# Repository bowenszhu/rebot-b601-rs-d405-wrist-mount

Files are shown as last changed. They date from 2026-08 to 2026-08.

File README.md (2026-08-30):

# reBot B601-RS RealSense D405 Wrist Mount

[简体中文](README.zh-CN.md) · [STEP/STL](hardware/release/) · [Design rationale](docs/design-rationale.md) · [Validation](docs/validation.md) · [Photo gallery](docs/photo-gallery.md)

<p align="center">
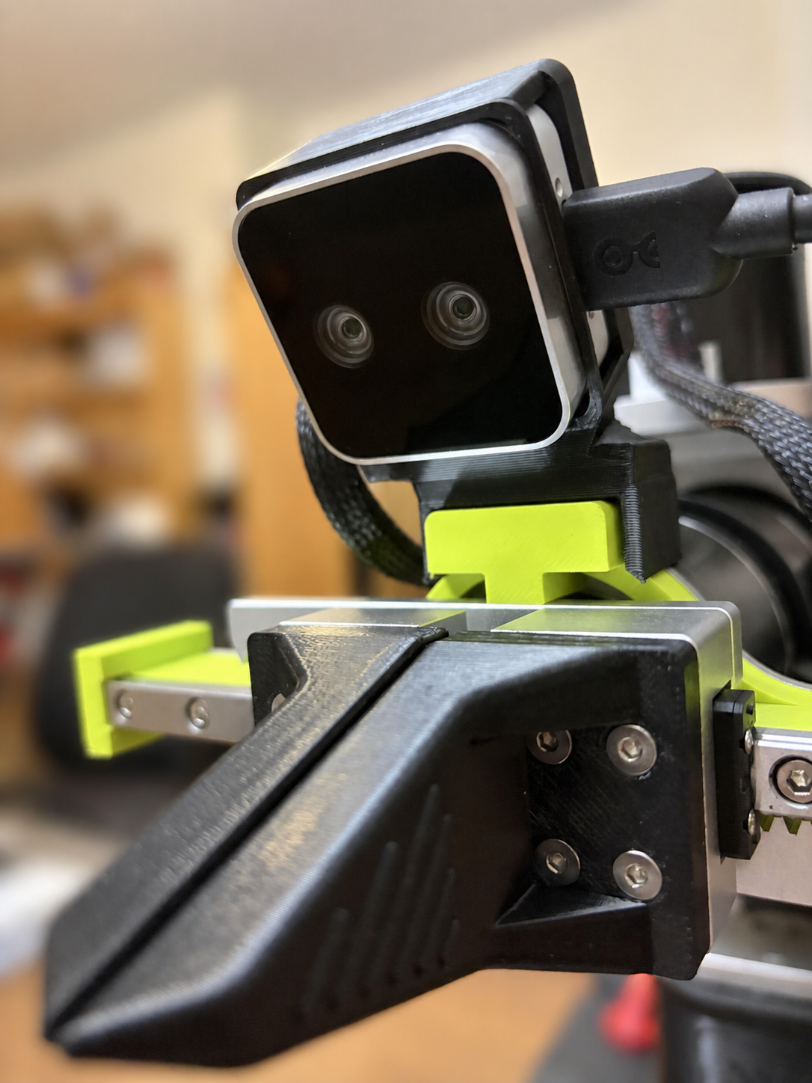
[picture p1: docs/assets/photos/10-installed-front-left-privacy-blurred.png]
30-degree D405 mount installed on the reBot B601-RS
  
</p>

A B601-RS-specific, open-hardware **30° downward eye-in-hand mount** for the [Seeed reBot Arm B601-RS](https://github.com/Seeed-Projects/reBot-DevArm) and [RealSense D405](https://www.realsenseai.com/products/stereo-depth-camera-d405/).

The design preserves Seeed's full D405 cradle and B601 wrist interface, then applies:

- **30° fixed downward pitch** — the largest integer pitch satisfying both tested clearance and working-distance boundaries at this fixed location;
- **9 mm lateral shift** — aligns the D405 left-imager optical reference, rather than the aluminium housing center, with the gripper centerline;
- **6 mm lift** — preserves conservative lower-front camera clearance as pitch increases;
- **solid lofted transition** — fills the side notch and creates a substantial load path;
- **unchanged handedness and USB side** — the cradle is not mirrored.

> “Best” means the best **validated general-purpose compromise under the stated B601-RS geometry and constraints**. It is not a universal optimum for every task or pose.

## Stock vs redesigned mount

| Seeed-derived stock ~15° | Redesigned 30° |
| --- | --- |
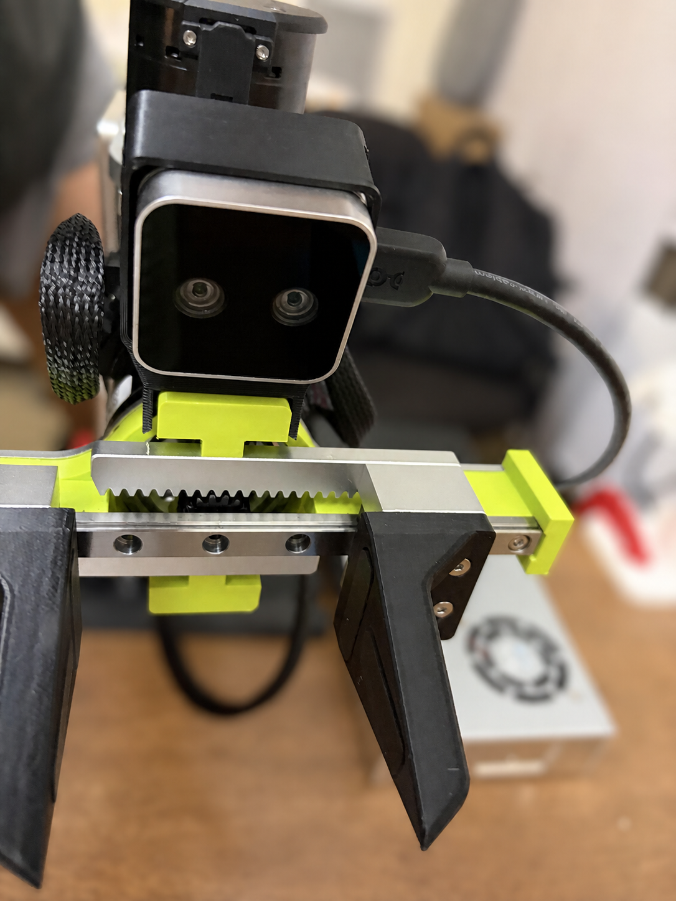
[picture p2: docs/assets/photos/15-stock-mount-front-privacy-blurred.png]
Stock mount
|  | Redesigned mount |

The upstream source is Seeed's [`D405_305_Mount.step`](https://github.com/Seeed-Projects/reBot-DevArm/blob/590ff16c51099a15a34abb339c6364355fde9235/hardware/reBot_B601_DM/3D_Printed_Parts/D405_305_Mount.step) at pinned commit [`590ff16c51099a15a34abb339c6364355fde9235`](https://github.com/Seeed-Projects/reBot-DevArm/tree/590ff16c51099a15a34abb339c6364355fde9235). Although that file lives under Seeed's B601-DM directory, the compatible interface and this derivative were physically fitted on the **B601-RS** shown here. This repository does not claim B601-DM validation.

## Download

| File | Use |
| --- | --- |
| [STEP](hardware/release/rebot_b601_rs_d405_mount_30deg.step) | Preferred manufacturing/CAD file |
| [STL](hardware/release/rebot_b601_rs_d405_mount_30deg.stl) | Ready-to-slice mesh |
| [geometry JSON](hardware/release/rebot_b601_rs_d405_mount_30deg.geometry.json) | Machine-readable pose, dimensions, and validation metadata |

[GitHub Release v1.0.0](https://github.com/bowenszhu/rebot-b601-rs-d405-wrist-mount/releases/tag/v1.0.0) contains the same three files.

Physically manufactured examples used:

- PETG, standard FDM, 100% infill, black;
- ABS, standard FDM, 60% infill, black.

See [printing and installation](docs/printing-and-installation.md).

## D405 properties that drive the design

The RealSense D405 product page specifies an **ideal range of 7–50 cm**, **87° × 58° depth FOV**, global shutters, and RGB generated by the **left imager plus ISP**, without a separate RGB camera; see [“Small features, high impact → RGB without a dedicated RGB” and “Tech Specs → RGB → Technology”](https://www.realsenseai.com/products/stereo-depth-camera-d405/). The [D400 Calibration Tools User Guide, §2.1 “Calibration Parameters”](https://dev.realsenseai.com/docs/calibration-tools-user-guide-for-intel-realsense-d400-series/) states: “The left camera is the reference camera and is located at world origin.” These facts create three constraints:

1. see the gripper and near workspace without treating targets inside the 7 cm ideal near boundary as reliable depth;
2. align the left optical reference, which is not the center of the 42 mm housing;
3. prevent the lower-front camera corner from approaching the green gripper structure as pitch increases.

The official [D400 datasheet, Figure 10-13 on PDF page 146](https://realsenseai.com/wp-content/uploads/2025/09/Intel-RealSense-D400-Series-Datasheet-October-2025.pdf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) supplies the 42 × 42 × 23 mm envelope, 20.00 mm rear M3 spacing, and 4.0 mm maximum insertion depth.

## Why 30°

A 20°–36° sweep at 1° increments used two task-independent boundaries:

- conservative D405-to-green-part clearance should remain approximately at or above the validated stock baseline (~9 mm in simulation, ~10 mm measured physically);
- optical reference to the TCP proxy should remain at least 70 mm, matching the D405's published ideal near-range boundary.

| Pitch | D405–green clearance | Optical reference–TCP proxy | Result |
| ---: | ---: | ---: | --- |
| 29° | 9.53 mm | 70.8 mm | feasible |
| **30°** | **9.12 mm** | **70.2 mm** | selected boundary solution |
| 31° | 8.71 mm | 69.6 mm | violates both conservative boundaries |

Interpolating ~30.3° would be false precision: print, seating, mesh, and calibration uncertainty are larger than 0.3°. Task-specific cube/tray pixel counts were examined but were **not** used as the general angle selector.

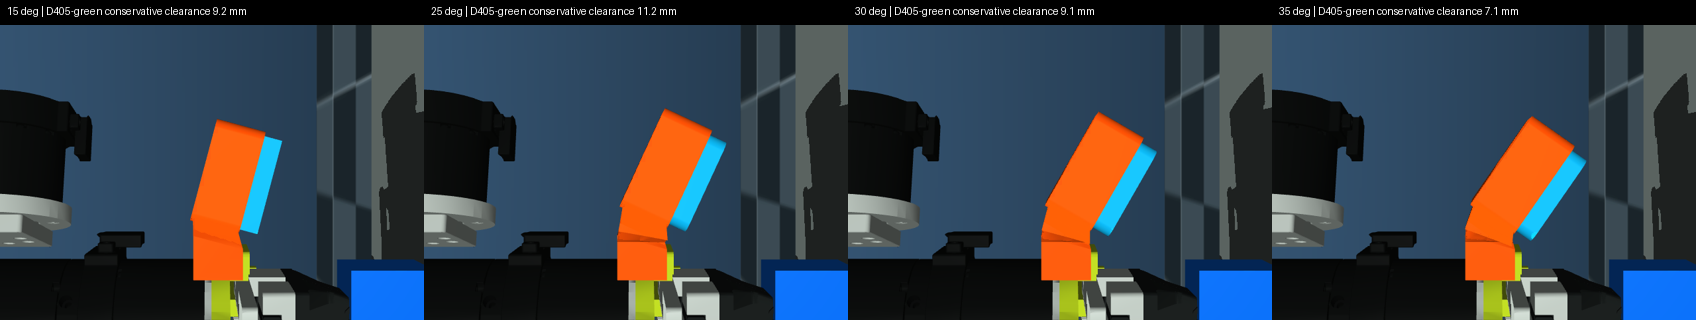
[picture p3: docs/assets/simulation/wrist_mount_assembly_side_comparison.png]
MuJoCo angle and assembly comparison


## Why shift 9 mm

The [D405's 18 mm stereo baseline, shown on PDF page 146](https://realsenseai.com/wp-content/uploads/2025/09/Intel-RealSense-D400-Series-Datasheet-October-2025.pdf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) places the left imager 9 mm from the stereo/housing midpoint. Keeping the Seeed handedness, the entire cradle moves **−9 mm in CAD X**:

```text
target left-imager X = 0
housing center X      = -9 mm
left-imager offset    = +9 mm
```

Seat, side/top wrap, bottom ledge, backplate, USB opening, and camera body move as one rigid system. Moving only the backplate would make the assembly inconsistent.

## Correcting the inherited 1 mm rear-hole offset

The pinned Seeed STEP has a 46 mm cradle centered at `X=0.00146 mm`, while the two rear holes are centered at `X=1.00146 mm`: a measured **+1.000 mm source offset**. [RealSense Figure 10-13, PDF page 146](https://realsenseai.com/wp-content/uploads/2025/09/Intel-RealSense-D400-Series-Datasheet-October-2025.pdf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) specifies a centered 20.00 mm M3 pair on the 42 mm body.

The published design fills the inherited 3.2/5.6 mm passages, then cuts the corrected pair **−1.000 mm** at 3.6/6.0 mm print-clearance diameters. It retains the exact 20.000 mm spacing.

```bash
conda run -n rebot-d405-cad python src/inspect_source_hole_alignment.py
```

D405 hole alignment correction

The 30° design was physically manufactured and installed; that installation exposed the source alignment issue. The published CAD includes the measured correction and passes single-solid, manifold-mesh, corrected-axis, passage, handedness, load-path, and D405-envelope checks.

## Physical D405 output

These are full 640×480 frames produced by the D405 while mounted on the B601-RS—not MuJoCo renders. The historical stock-mount run on 2026-08-24 recorded RGB only. The redesigned-mount capture on 2026-08-30 recorded synchronized RGB and raw `uint16` depth aligned to RGB after a 120-frame warm-up.

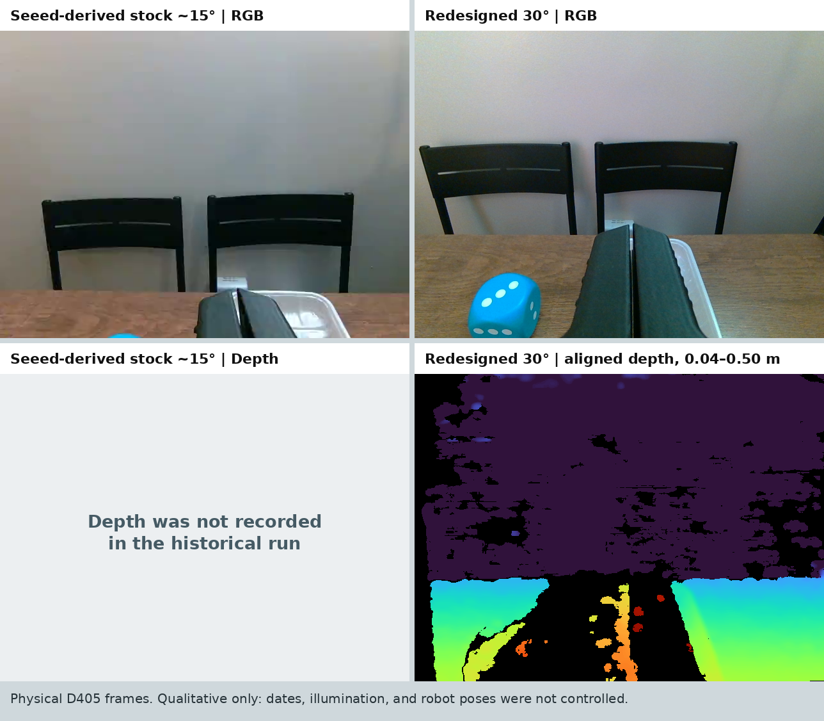
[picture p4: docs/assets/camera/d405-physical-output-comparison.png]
Physical D405 RGB and depth output, stock mount versus redesigned mount


The physical frames show the intended qualitative change: with the redesigned mount, the gripper occupies the image center and more of the near workspace, including the blue cube, enters the frame. They are **not a controlled quantitative experiment**: capture dates, illumination, and robot poses differed. The missing historical depth panel is deliberately left blank rather than reconstructed. See the [source RGB frames, redesigned raw 16-bit depth, colorized depth](docs/assets/camera/) and [machine-readable provenance](data/physical_d405_capture_provenance.json).

## Controlled synthetic RGB + depth comparison

The image below uses the same MuJoCo grasp pose for stock 15° and the redesigned 30° mount. It is explicitly synthetic, and complements rather than replaces the physical frames above.

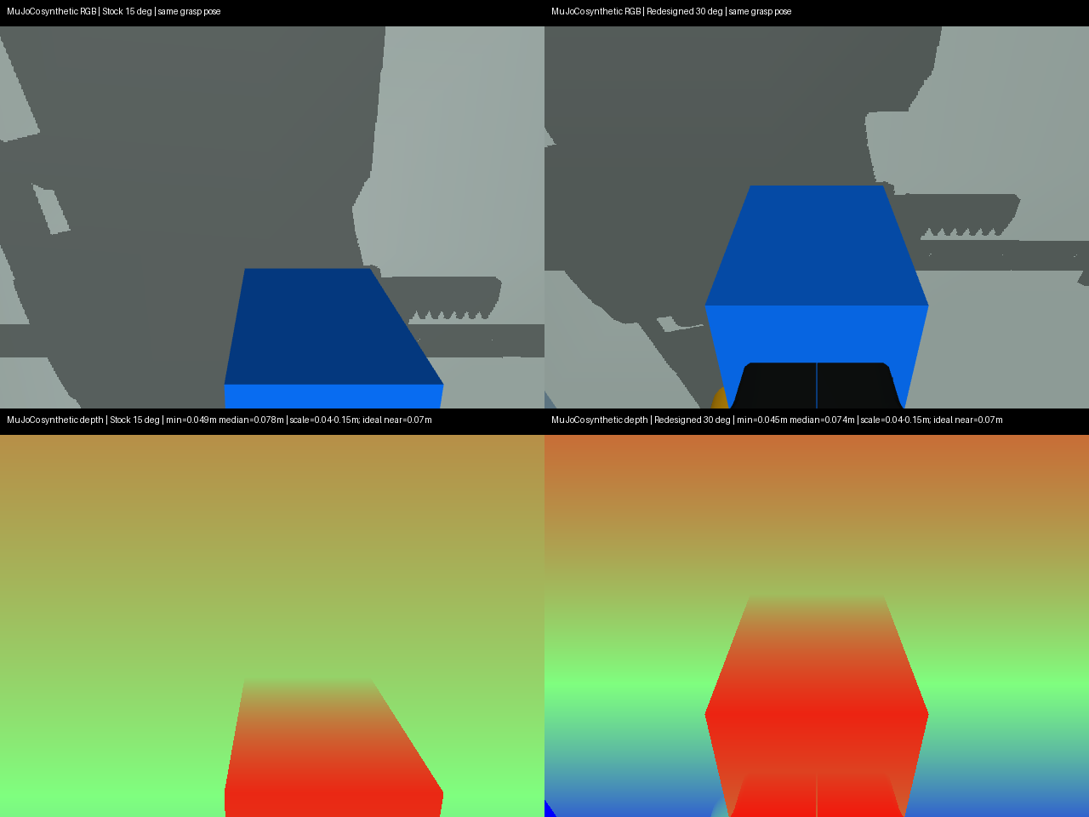
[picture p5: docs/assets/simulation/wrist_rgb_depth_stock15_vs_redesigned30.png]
MuJoCo synthetic RGB and depth, stock 15 degrees versus redesigned 30 degrees


The colorized synthetic depth row uses a 0.04–0.15 m near-manipulation scale and labels the D405's 0.07 m ideal near boundary. A controlled physical before/after RGB-D capture remains future work because the stock-mount run did not record depth.

## Reproduce CAD and MuJoCo from the README

CAD uses its own Conda environment:

```bash
conda env create -f environment-cad.yml
conda activate rebot-d405-cad
python src/design_mount.py --angles 25 30 35
python src/validate_outputs.py build --angles 25 30 35
```

MuJoCo validation used [`ReBot_Arm_web_RS@d289fa7`](https://github.com/Yang-Ci/ReBot_Arm_web_RS/tree/d289fa7202ad7da9595a480b29397d70efacc4c1). Its robot assets are not vendored because that pinned commit exposes no repository-level license.

```bash
git clone https://github.com/Yang-Ci/ReBot_Arm_web_RS.git external/ReBot_Arm_web_RS
git -C external/ReBot_Arm_web_RS checkout d289fa7202ad7da9595a480b29397d70efacc4c1
python3 -m venv .venv-sim
.venv-sim/bin/pip install -r requirements-simulation.txt
export REBOT_MUJOCO_MODEL="$PWD/external/ReBot_Arm_web_RS/rebotarm_ros2/src/rebotarm_mujoco_rs/models/rs_grasp_scene.xml"
MUJOCO_GL=egl .venv-sim/bin/python simulation/simulate_fov.py
MUJOCO_GL=egl .venv-sim/bin/python simulation/sweep_angles.py
```

Detailed limitations are in [simulation.md](docs/simulation.md). MuJoCo is a screen, not physical collision certification or camera extrinsic calibration.

## More physical views

| New mount side pitch and USB access | New mount rear screws and transition |
| --- | --- |
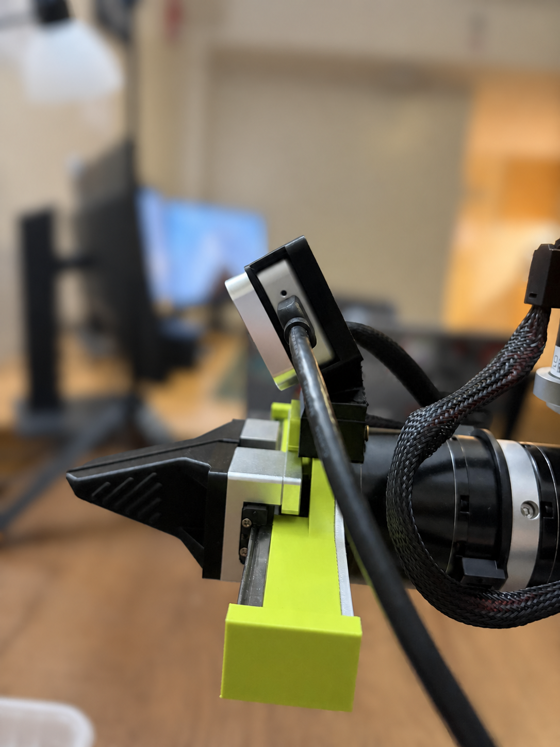
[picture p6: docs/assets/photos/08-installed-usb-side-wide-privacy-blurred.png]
New mount side view
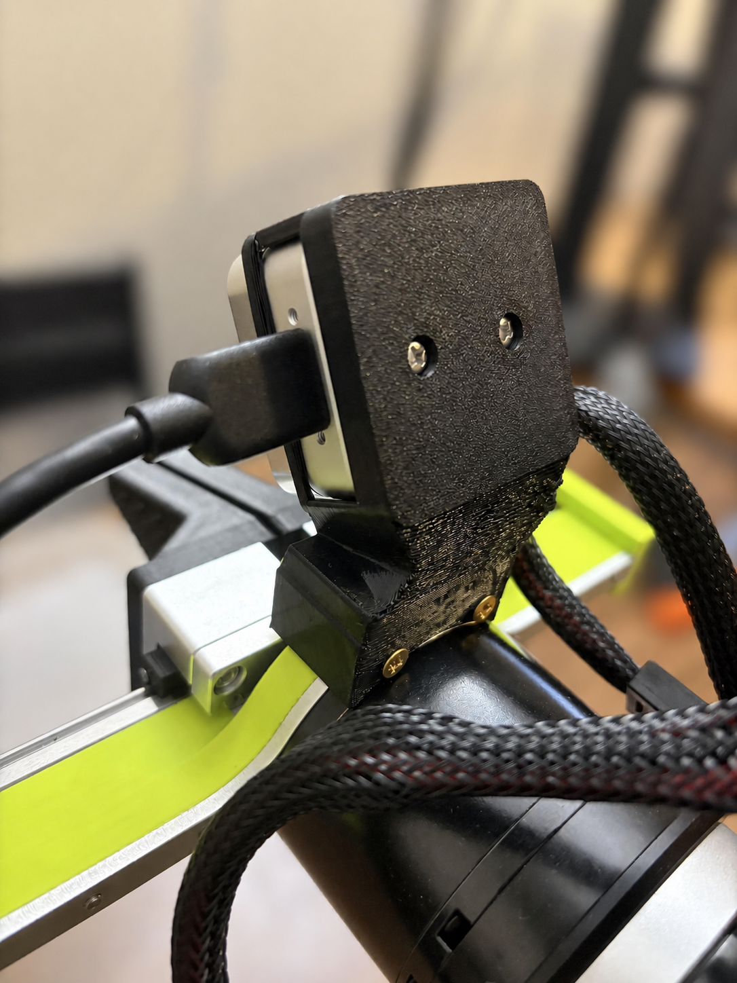
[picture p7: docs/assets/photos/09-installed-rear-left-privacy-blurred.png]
New mount rear view
|  |  |

| Printed cradle | Stock mount side reference |
| --- | --- |
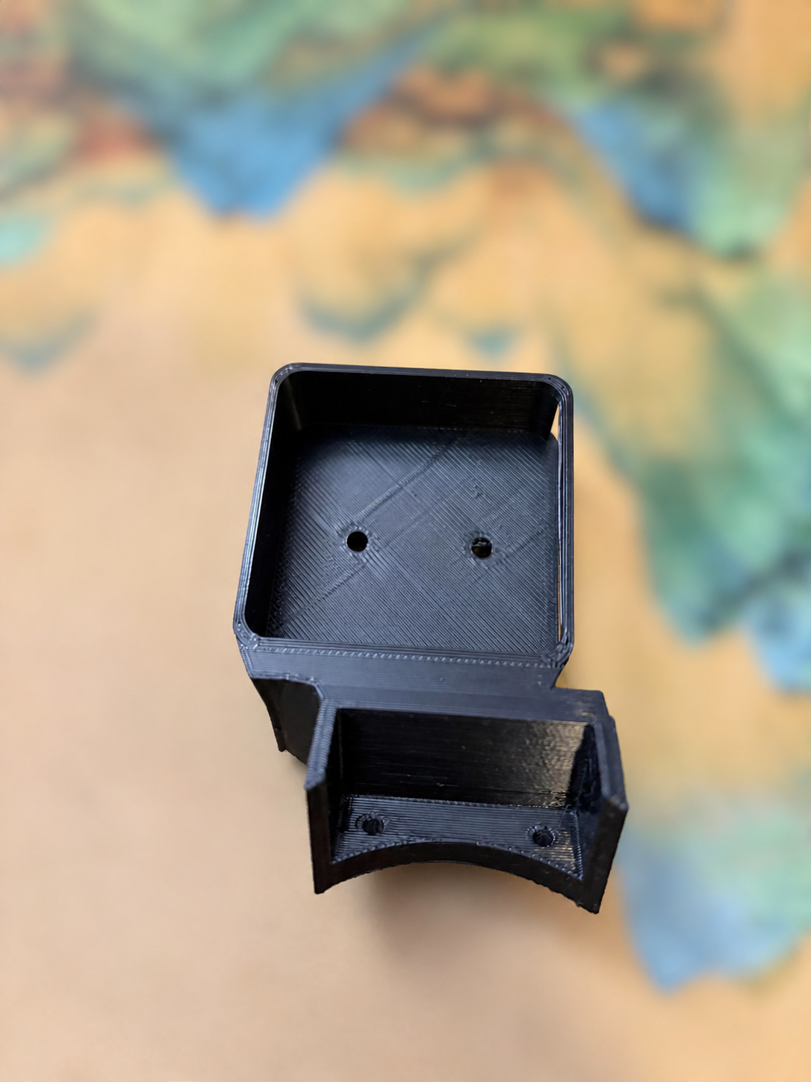
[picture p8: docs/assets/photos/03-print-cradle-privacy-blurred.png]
Printed cradle
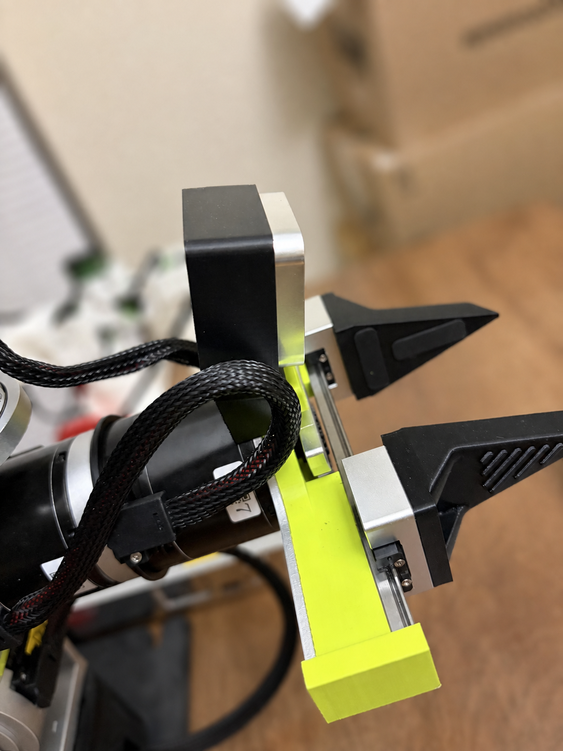
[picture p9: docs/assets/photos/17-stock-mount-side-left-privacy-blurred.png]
Stock mount side
|  |  |

The photographs illustrate assembly; dimensions come from CAD and machine-readable validation. See all 16 images in the [photo gallery](docs/photo-gallery.md).

## Validation status

- 30° design physical manufacturing and installation: passed;
- corrected STEP: one valid solid;
- corrected STL: closed, connected, manifold;
- added adapter vs D405 envelope: `0.0000 mm³`;
- corrected source-hole fill volume: ~`212.1 mm³`;
- powered full-workspace collision sweep and long-duration thermal test: not claimed.

## Safety

- Disconnect robot motor power for first installation and manual clearance checks.
- D405 rear holes are `2× M3×0.5`, maximum insertion depth 4.0 mm. Check screw length against printed backplate thickness; never bottom a screw inside the camera.
- Seat the camera fully and tighten both screws gradually and alternately.
- Verify gripper opening, USB access, cable slack, and an unpowered wrist sweep before powered motion.

## Attribution and license

Designed and validated by **Bowen Zhu**. Reuse requires the applicable license notice and attribution.

- hardware and hardware-design source: CERN-OHL-W-2.0;
- original software: MIT;
- original documentation and photographs: CC BY 4.0.

See [LICENSE.md](LICENSE.md), [ATTRIBUTION.md](ATTRIBUTION.md), and [primary references](docs/references.md). This is an independent community project, not an official Seeed or RealSense product.

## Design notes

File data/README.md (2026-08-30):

# Validation data

| File | Meaning |
| --- | --- |
| `wrist_rgb_angle_sweep_1deg.csv` | Reproduced 20°–36° sweep at 1° increments and five proxy stages |
| `wrist_rgb_factory_calibrated_metrics.csv` | Reproduced rendered metrics for 15°/25°/30°/35° |
| `historical_wrist_fov_15_25_35_45_metrics.csv` | Early camera-only stress screen; retained as historical evidence, not the angle selector |
| `seeed_source_hole_alignment.json` | Direct CadQuery measurement of the pinned Seeed cradle center, rear-hole axes, +1 mm offset, and −1 mm correction |
| `physical_d405_capture_provenance.json` | Source paths, timestamps, hashes, calibration values, and limitations for the physical D405 RGB/depth comparison |

Floating-point last digits may differ across MuJoCo/NumPy/platform builds. Interpret the published millimetre-scale boundaries at physically meaningful precision.

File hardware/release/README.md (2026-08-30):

# 30° release

This is the single public release set for the Seeed reBot B601-RS / RealSense D405 mount.

| File | SHA-256 | Purpose |
| --- | --- | --- |
| `rebot_b601_rs_d405_mount_30deg.step` | `363c1e3f710760c0cd875668e1dd60884a66ba971799836d5476cf80ac8b4f50` | Preferred manufacturing/CAD file |
| `rebot_b601_rs_d405_mount_30deg.stl` | `bf9ffe0eafc1c5f34afeac5485eced94ce3dc87977e3a995142e9cda287930d0` | Ready-to-slice mesh |
| `rebot_b601_rs_d405_mount_30deg.geometry.json` | `52606d9e267c3cf14d4a21f0ea51bb1cd08721ee84f32736ec62364912ff952b` | Pose, geometry, source-hole measurement, and correction metadata |

The 30° design was physically manufactured and installed. That installation exposed a small inherited alignment issue: the pinned Seeed [`D405_305_Mount.step`](https://github.com/Seeed-Projects/reBot-DevArm/blob/590ff16c51099a15a34abb339c6364355fde9235/hardware/reBot_B601_DM/3D_Printed_Parts/D405_305_Mount.step) centers its rear M3 pair 1.000 mm from the cradle center. The published files fill those inherited passages and recut a centered, 20.000 mm-spaced pair at 3.6/6.0 mm print-clearance diameters, matching the [RealSense D405 mechanical drawing, PDF page 146](https://realsenseai.com/wp-content/uploads/2025/09/Intel-RealSense-D400-Series-Datasheet-October-2025.pdf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).

Automated validation reports ~212.1 mm³ source-hole fill, exactly two corrected through/counterbore axes with no residual old axes, one valid STEP solid, a closed/connected/manifold STL, substantial transition overlap, and zero added D405-envelope collision.

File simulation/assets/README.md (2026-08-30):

# Simulation-only assets

`seeed_original_d405_15deg.stl` is a tessellated derivative of the pinned Seeed `D405_305_Mount.step` and is used only as the stock-angle comparison mesh. It remains under CERN-OHL-W-2.0; see [`hardware/vendor/seeed-rebot-devarm/`](../../hardware/vendor/seeed-rebot-devarm/).

Do not send this simulation mesh to a print service; use the reviewed 30° STEP/STL in [`hardware/release/`](../../hardware/release/).

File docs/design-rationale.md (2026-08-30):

# Design rationale

[简体中文](design-rationale.zh-CN.md)

## 1. Problem statement

The pinned Seeed [`D405_305_Mount.step`](https://github.com/Seeed-Projects/reBot-DevArm/blob/590ff16c51099a15a34abb339c6364355fde9235/hardware/reBot_B601_DM/3D_Printed_Parts/D405_305_Mount.step) for D405/Gemini 305 was a useful physical and licensing baseline, but its approximately 15° pose did not provide the desired near-field wrist view. A replacement had to improve eye-in-hand visibility without inventing a new camera retention system or sacrificing physical fit.

The source STEP is pinned at Seeed commit [`590ff16c51099a15a34abb339c6364355fde9235`](https://github.com/Seeed-Projects/reBot-DevArm/tree/590ff16c51099a15a34abb339c6364355fde9235) and is located in the B601-DM directory. The compatible interface and derivative described here were physically fitted on a B601-RS; this project deliberately limits its support claim to B601-RS.

The design objectives were therefore separated into independent questions:

1. **Compatibility:** does it use the actual B601 wrist interface and D405 envelope?
2. **Optical reference:** which point should align with the gripper centerline?
3. **Pitch:** how much downward view can be gained before violating clearance or useful range?
4. **Strength:** can the transformed cradle reconnect to the original base through a robust printable load path?
5. **Reproducibility:** can every geometric claim be regenerated and checked?

## 2. Coordinate convention

The design inherits the Seeed STEP coordinates, in millimetres:

- `X`: left/right across the gripper;
- `Y`: from the wrist toward the camera;
- `Z`: forward along the gripper.

Positive pitch points the camera optical axis toward `−Y`, down toward the tabletop. The Seeed cradle's handedness is retained. Camera, wrap, USB opening, backplate, and camera holes are always transformed as one rigid body.

## 3. Why align the left imager

The D405 product page sections [“Small features, high impact → RGB without a dedicated RGB” and “Tech Specs → RGB → Technology”](https://www.realsenseai.com/products/stereo-depth-camera-d405/) explain that the global-shutter D405 has no separate RGB sensor and uses **left-imager RGB with ISP**. The [D400 Calibration Tools User Guide, §2.1 “Calibration Parameters”](https://dev.realsenseai.com/docs/calibration-tools-user-guide-for-intel-realsense-d400-series/) states: “The left camera is the reference camera and is located at world origin.” The [Depth Post-Processing guide, “2. Edge-preserving filtering”, occlusion paragraph](https://dev.realsenseai.com/docs/depth-post-processing-for-intel-realsense-depth-camera-d400-series/) adds: “Since we reference everything to the left imager...”

The [D405 mechanical drawing, PDF page 146](https://realsenseai.com/wp-content/uploads/2025/09/Intel-RealSense-D400-Series-Datasheet-October-2025.pdf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) gives an 18 mm stereo baseline. With the stereo midpoint aligned to the 42 mm housing center, the left imager is 9 mm from that midpoint. Centering the aluminium box would therefore leave the optical reference offset from the gripper centerline.

In the preserved Seeed handedness, the left-imager offset is `+9 mm` in CAD X. The required rigid translation is:

```text
desired left-imager X = 0 mm
original left-imager X = +9 mm
cradle translation X = 0 − 9 = −9 mm
```

The factory 640×480 color profile was also read from the physical camera and used in the visibility rendering: vertical FOV `62.82°`, principal point approximately `(323.24, 235.99)` pixels. MuJoCo uses a centered principal point, so the residual few-pixel offset and lens distortion remain outside this first-order model.

## 4. Why not move only the backplate

The camera is retained by a connected system: lower shelf, side wraps, top wrap, backplate, two camera holes, and the USB opening. Moving only the plate would detach screw axes from the seat and side supports.

The generator therefore extracts the **complete original cradle**, applies a single rigid transform, and checks that its symmetric-difference volume relative to the original is `0 mm³` before transformation. This proves that tilt and lateral centering do not silently deform or mirror the inherited fit geometry.

## 5. Why add a 6 mm lift

Pitching about the lower-rear datum swings the D405's lower-front corner down and back toward the green wrist structure. Pitch alone would consume the original clearance.

The cradle is raised 6 mm before reconnection. This places the 30° lower-front camera corner near the conservative position of the stock 15° installation. The choice is then checked against the complete D405 envelope and green-part mesh in MuJoCo rather than accepted from CAD appearance alone.

## 6. How the 30° pitch was selected

### 6.1 What was scanned

- coarse rendered comparison: 15°, 25°, 30°, 35° (and a 45° stress case);
- fine sweep: 20°–36°, 1° increments;
- full-size D405 envelope placed at the left optical reference;
- actual B601-RS MuJoCo scene and green gripper mesh;
- factory-derived D405 640×480 color intrinsics for view rendering.

Task objects and proxy pick/place poses were rendered to understand visibility, but **task-object pixel area was not used to choose the general-purpose angle**.

### 6.2 Task-independent constraints

Two constraints define the upper pitch boundary at this fixed mount location:

1. **Mechanical clearance:** retain approximately the conservative stock margin. The stock 15° design measured roughly 10 mm physically; the conservative mesh model reports 9.17 mm. A ~9 mm simulation floor is therefore a reasoned baseline, not a manufacturing tolerance certificate.
2. **Near working distance:** keep the optical reference at least 70 mm from the TCP proxy. RealSense publishes 7 cm as the D405 ideal-range near boundary at the relevant 480p class of operation.

Fine-sweep results around the boundary:

| Angle | D405–green clearance | Optical-to-TCP proxy | Decision |
| ---: | ---: | ---: | --- |
| 29° | 9.53 mm | >70 mm | feasible |
| **30°** | **9.12 mm** | **70.2 mm** | selected |
| 31° | 8.71 mm | 69.6 mm | rejected |

The two constraints cross near 30°. Linear interpolation produces about 30.3°, but print, screw, seating, mesh, and camera-model uncertainty are much larger than 0.3°. The defensible output is the integer 30°, not a false-precision decimal.

### 6.3 Why not 35° or 45°

35° improves near-field visibility but reduces conservative D405–green clearance to about 7.06 mm and pushes some targets inside the D405's ideal near range. At 45°, the camera becomes conspicuously forward/downward and the fixed-location assumption is no longer a sensible general-purpose compromise.

If a future task requires more gripper/TCP visibility, the correct redesign is to move the camera farther back/up while recomputing visibility and clearance—not simply to keep increasing pitch.

## 7. Why the transition is solid

The original base is retained through CAD `Y=42 mm`; transformed cradle material is retained down to `Y=38 mm`. A single closed profile from the original `Y=39 mm` section is lofted between the two poses.

This produces a filled transition rather than two touching walls or a cosmetic skin. Validation requires substantial solid overlap with both sides:

- adapter-to-base overlap: about `2.00 cm³`;
- adapter-to-cradle overlap: about `0.75 cm³`;
- new adapter collision with the D405 engineering envelope: `0.0000 mm³`.

The redesigned 30° solid volume is approximately `32.48 cm³`, about `3.43 cm³` above the original. The increase is intentional material for the filled notch and load path.

## 8. Why the published design corrects the camera holes by 1 mm

The [RealSense D405 mechanical drawing, PDF page 146](https://realsenseai.com/wp-content/uploads/2025/09/Intel-RealSense-D400-Series-Datasheet-October-2025.pdf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) specifies two rear `M3×0.5` holes at 20.00 mm spacing, centered on the 42 mm body. Direct measurement of the pinned Seeed STEP found:

- cradle X envelope: `−22.9985446 .. +23.0014556 mm`, center `+0.0014555 mm`;
- rear hole axes: `−8.9985445` and `+11.0014555 mm`, pair center `+1.0014555 mm`;
- source pair offset relative to cradle: **+1.0000000 mm**.

The manufactured 30° design inherited that offset. Its 3.6 mm clearance holes allowed the physical camera to assemble, but clearance should not be used to hide a known source error.

The published geometry therefore fills the source 3.2 mm through holes and 5.6 mm counterbores (~212.1 mm³ restored material), then recuts a centered pair at:

- 3.6 mm through diameter;
- 6.0 mm counterbore diameter;
- exact 20.000 mm axis spacing;
- **−1.000 mm correction** relative to the Seeed source pair.

The camera itself contains the M3 threads; the printed plate is a clearance/clamping component, not a threaded nut. The widened print passages still tolerate FDM/MJF/SLS shrink, while the corrected axes now agree with the D405 drawing. The correction is included in the release and is covered by export-level axis checks.

## 9. Handedness and USB access

Facing the camera front, the left imager appears on the observer's right. Viewer default viewpoints can make the asymmetric part appear mirrored. The authoritative handedness reference is the previously printed Seeed part and the physical USB side—not a CAD viewer screenshot.

The source cradle is not mirrored, and the D405 must not be installed upside-down or rotated 180°. The USB opening moves with the cradle and remains on the physical connector side.

## 10. What this design does not prove

- exact camera extrinsics after printing and screw tightening;
- collision-free powered motion throughout the entire robot workspace;
- long-duration thermal behavior under every D405 stream configuration;
- structural fatigue life or impact certification;
- optimality for a different camera, gripper, mounting block, or task distribution.

For RGB-D research, calibrate the installed camera extrinsics. Treat CAD pose as an initialization, not ground truth.

Primary references are collected in [references.md](references.md). Raw sweep tables are in [`data/`](../data/).

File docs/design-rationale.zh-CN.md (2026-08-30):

# 设计论证

[English](design-rationale.md)

## 1. 问题是什么

固定版本的Seeed [`D405_305_Mount.step`](https://github.com/Seeed-Projects/reBot-DevArm/blob/590ff16c51099a15a34abb339c6364355fde9235/hardware/reBot_B601_DM/3D_Printed_Parts/D405_305_Mount.step)为D405/Gemini 305提供了可靠的机械接口和许可证基线，但约15°姿态不能充分满足近场腕上视角。新设计需要改善eye-in-hand可见性，同时不能重新发明未经验证的相机夹持结构。

源STEP固定在Seeed commit [`590ff16c51099a15a34abb339c6364355fde9235`](https://github.com/Seeed-Projects/reBot-DevArm/tree/590ff16c51099a15a34abb339c6364355fde9235)，位于B601-DM目录；这里使用的兼容接口和衍生设计已在B601-RS上完成实体适配，所以本项目有意只对B601-RS作支持声明。

因此我们把问题拆成互相独立的五项：

1. **兼容性**：是否真正使用 B601 腕部接口和 D405 外形？
2. **光学参考**：应让哪个点对齐夹爪中心？
3. **俯角**：增加到多少会越过机械间隙或有效工作距离？
4. **强度**：变换后的相机托架能否通过可靠、可打印的承力路径重新连接到底座？
5. **可复现性**：每条几何结论能否重新生成和自动检查？

## 2. 坐标约定

设计继承 Seeed STEP 的毫米坐标：

- `X`：夹爪左右方向；
- `Y`：从腕部指向相机；
- `Z`：沿夹爪向前。

正俯角让相机光轴指向 `−Y`，也就是桌面方向。Seeed 原版托架左右方向保持不变；相机座、包边、USB 开口、背板和相机孔始终作为同一个刚体变换。

## 3. 为什么对齐左成像器

D405产品页的[“Small features, high impact → RGB without a dedicated RGB”和“Tech Specs → RGB → Technology”](https://www.realsenseai.com/products/stereo-depth-camera-d405/)说明D405没有独立RGB传感器，而是使用**left-imager RGB with ISP**。[D400 Calibration Tools User Guide §2.1 “Calibration Parameters”](https://dev.realsenseai.com/docs/calibration-tools-user-guide-for-intel-realsense-d400-series/)明确写道：“The left camera is the reference camera and is located at world origin.” [Depth Post-Processing指南“2. Edge-preserving filtering”后讨论occlusion的段落](https://dev.realsenseai.com/docs/depth-post-processing-for-intel-realsense-depth-camera-d400-series/)进一步写道：“Since we reference everything to the left imager...”

[D405机械图，PDF第146页](https://realsenseai.com/wp-content/uploads/2025/09/Intel-RealSense-D400-Series-Datasheet-October-2025.pdf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)给出18 mm双目基线。以双目中点对齐42 mm外壳中心时，左成像器与中点相差9 mm。若只让铝壳居中，真正的光学参考仍会偏离夹爪中心线。

保持 Seeed 托架原始左右方向时，左成像器在 CAD X 方向偏移 `+9 mm`，所以刚体平移为：

```text
目标左成像器 X = 0 mm
原始左成像器 X = +9 mm
托架平移 X = 0 − 9 = −9 mm
```

仿真还读取了实物 D405 的 640×480 彩色 profile：垂直 FOV `62.82°`，主点约为 `(323.24, 235.99)` 像素。MuJoCo 相机采用居中主点，因此几像素残差和镜头畸变不在这项第一阶筛查范围内。

## 4. 为什么不能只移动背板

D405 依靠底部托举、左右包边、顶部包边、背板、两颗孔和 USB 开口共同定位。只移动背板会让螺丝轴线与相机座、侧边支撑分离。

生成器提取**完整原版托架**并施加一次刚体变换；变换前，托架与 Seeed 源实体的对称差必须为 `0 mm³`。这能证明倾角和平移没有暗中改变或镜像原版夹持几何。

## 5. 为什么再抬高 6 mm

若围绕后下方基准直接增大俯角，D405 前下角会向下、向后摆向绿色腕部结构，快速消耗原版间隙。

因此托架在重连之前向上补偿 6 mm，让 30° 的前下角接近原版 15° 的保守位置。之后仍必须在 MuJoCo 中用完整 D405 包络和绿色件 mesh 独立检查，不能只凭 CAD 画面判断。

## 6. 30°是怎么选出来的

### 6.1 扫描范围

- 粗对比：15°、25°、30°、35°，另有 45° 压力测试；
- 细扫描：20°–36°，1° 步长；
- 以左成像器为参考放置完整 D405 包络；
- 使用 B601-RS MuJoCo 场景和真实绿色夹爪 mesh；
- 视野渲染采用实机 D405 640×480 profile。

仿真也渲染了任务物体和抓取/放置代理姿态，用于理解可见性；但通用角度**不是按蓝方块或托盘像素面积选的**。

### 6.2 两条任务无关边界

1. **机械间隙**：大致保留原版保守余量。原版 15° 真机约 10 mm，保守 mesh 仿真为 9.17 mm，所以约 9 mm 是有依据的筛查线，而不是制造公差认证。
2. **最近工作距离**：光学参考到 TCP 代理目标不低于 70 mm，对应 RealSense 公布的 D405 理想近界 7 cm。

边界附近结果：

| 角度 | D405–绿色件间隙 | 光学参考–TCP代理 | 结论 |
| ---: | ---: | ---: | --- |
| 29° | 9.53 mm | >70 mm | 可行 |
| **30°** | **9.12 mm** | **70.2 mm** | 采用 |
| 31° | 8.71 mm | 69.6 mm | 拒绝 |

两条约束在 30°附近相交。线性插值约 30.3°，但打印、螺丝、就位、mesh 和相机模型误差都远大于 0.3°。因此可信结论是整数 30°，不是伪精确的 30.3°。

### 6.3 为什么不用35°或45°

35°虽然更容易看到近场，但保守间隙降到约 7.06 mm，部分目标也会进入 D405 理想近界以内。45°明显过度前倾，不再是当前固定安装位置的合理通用折中。

若未来任务确实需要让 TCP 更深入画面，正确方法是同时把相机向后/向上移动并重新计算，而不是继续单独增大俯角。

## 7. 为什么过渡部分填实

原版底座保留到 CAD `Y=42 mm`，变换后的托架向下保留到 `Y=38 mm`；使用原版 `Y=39 mm` 的同一个闭合截面在两个姿态之间一次放样。

它不是两个薄壁刚好相碰，而是完整实心过渡。验证要求：

- 过渡体与底座实体搭接约 `2.00 cm³`；
- 与托架实体搭接约 `0.75 cm³`；
- 对 D405 工程包络新增碰撞为 `0.0000 mm³`。

改造30°实体体积约`32.48 cm³`，比原版多约`3.43 cm³`；增加的材料用于填掉侧面凹口和建立承力路径。

## 8. 为什么发布设计把相机孔修正1 mm

[RealSense D405机械图，PDF第146页](https://realsenseai.com/wp-content/uploads/2025/09/Intel-RealSense-D400-Series-Datasheet-October-2025.pdf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)规定后部两颗`M3×0.5`孔间距20.00 mm，并以42 mm外壳中心对称。直接测量固定的Seeed STEP得到：

- 托架X包围盒：`−22.9985446 .. +23.0014556 mm`，中心`+0.0014555 mm`；
- 后部孔轴：`−8.9985445`与`+11.0014555 mm`，孔对中心`+1.0014555 mm`；
- 源孔对相对托架中心偏移：**+1.0000000 mm**。

实际制造的30°设计继承了这个偏移；3.6 mm宽松孔让真机仍能装上，但不能用装配余量掩盖已经量化的源错误。

发布几何先填平源3.2 mm通孔和5.6 mm沉孔（恢复约212.1 mm³材料），再重新切削：

- 3.6 mm通孔；
- 6.0 mm沉孔；
- 精确20.000 mm孔距；
- 相对Seeed源孔对 **−1.000 mm修正**。

真正的M3螺纹在D405金属外壳内，塑料背板只负责通孔和夹紧。放宽的打印孔仍可吸收FDM/MJF/SLS收缩，而修正后的轴线与D405官方图一致。修正已收入发布件，并由导出STEP孔轴检查覆盖。

## 9. 左右方向与USB

面对相机正面时，D405 左成像器位于观察者右侧。CAD 查看器的默认视角容易让非对称零件看起来像镜像；可靠基准是已成功打印的 Seeed 原件和真实 USB 插口方向。

本设计不镜像源托架，相机也不能上下颠倒或旋转 180°。USB 开口随完整托架一起变换，始终位于真实插口侧。

## 10. 本设计没有证明什么

- 打印并拧紧后的精确相机外参；
- 全工作空间通电运动绝对无碰撞；
- 所有 D405 模式下的长期温升；
- 结构疲劳寿命或冲击认证；
- 对其他相机、夹爪、绿色块或任务分布仍然最优。

开展 RGB-D 研究时，应标定安装后的相机外参；CAD 位姿只是初始化，不是真值。

一手来源汇总在 [references.md](references.md)，原始扫描表在 [`data/`](../data/)。

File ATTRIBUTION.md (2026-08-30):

# Attribution and upstream sources

## This project

- Design, analysis, documentation, physical validation, and photographs: **Bowen Zhu**, 2026.
- Suggested attribution: `Bowen Zhu, reBot B601-RS D405 Wrist Mount, https://github.com/bowenszhu/rebot-b601-rs-d405-wrist-mount`.

## Seeed open-hardware source

The mechanical interface and complete D405 cradle are derived from Seeed-Projects' `D405_305_Mount.step`:

- Repository: <https://github.com/Seeed-Projects/reBot-DevArm>
- Pinned commit: [`590ff16c51099a15a34abb339c6364355fde9235`](https://github.com/Seeed-Projects/reBot-DevArm/tree/590ff16c51099a15a34abb339c6364355fde9235)
- Original file: [`hardware/reBot_B601_DM/3D_Printed_Parts/D405_305_Mount.step`](https://github.com/Seeed-Projects/reBot-DevArm/blob/590ff16c51099a15a34abb339c6364355fde9235/hardware/reBot_B601_DM/3D_Printed_Parts/D405_305_Mount.step)
- License: CERN-OHL-W-2.0
- Vendored source SHA-256: `99df53e11fcdd192830ef205d080db310448cc39b891b62a8f64316f6565c28d`

The new mount preserves the upstream wrist interface and complete camera cradle, then applies a rigid 30° pitch, a 9 mm lateral shift, a 6 mm lift, print-clearance holes, a rounded exposed tip, and a solid lofted transition.

## MuJoCo validation environment

The validation renderer used a pinned local checkout of:

- Repository: <https://github.com/Yang-Ci/ReBot_Arm_web_RS>
- Commit: [`d289fa7202ad7da9595a480b29397d70efacc4c1`](https://github.com/Yang-Ci/ReBot_Arm_web_RS/tree/d289fa7202ad7da9595a480b29397d70efacc4c1)

That repository did not expose a repository-level license at the pinned commit. Its source and meshes are not redistributed here. Published screenshots are marked as third-party-containing documentation images and are not covered by this project's CC BY grant.

## RealSense references

RealSense and D405 are trademarks/product names of their respective owners. This project is independent and is not endorsed by RealSense or Seeed Studio.

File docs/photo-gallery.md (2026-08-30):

# Physical photo gallery / 真机实拍图库

All 16 physical photographs are included. These images document appearance and assembly only—use CAD and validation metadata for dimensional evidence.

全部16张实拍均已收入仓库。照片用于记录外观和装配；尺寸结论以CAD和验证元数据为准。

## Printed part / 打印件

| Rear / 背面 | Side / 侧面 |
| --- | --- |
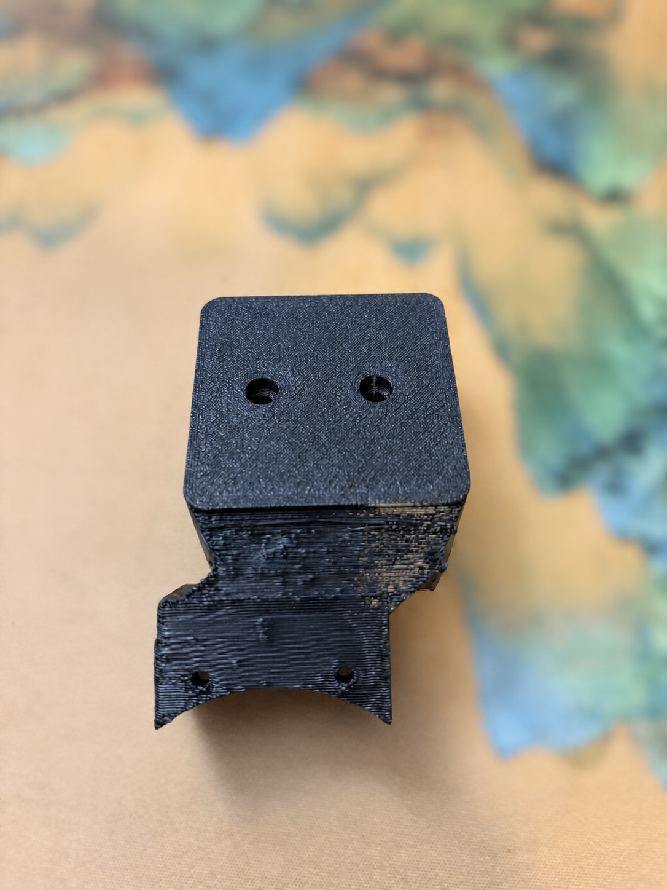
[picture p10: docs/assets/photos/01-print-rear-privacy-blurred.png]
Printed mount rear
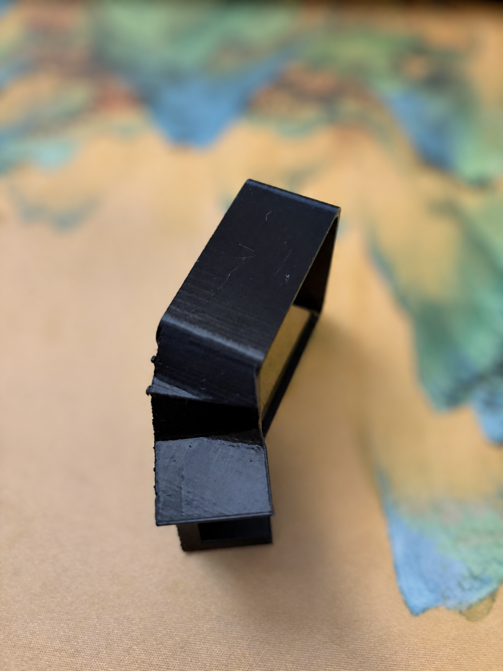
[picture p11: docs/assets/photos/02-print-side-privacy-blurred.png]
Printed mount side
|  |  |

| Camera cradle / 相机托架内部 | Opposite side / 另一侧 |
| --- | --- |
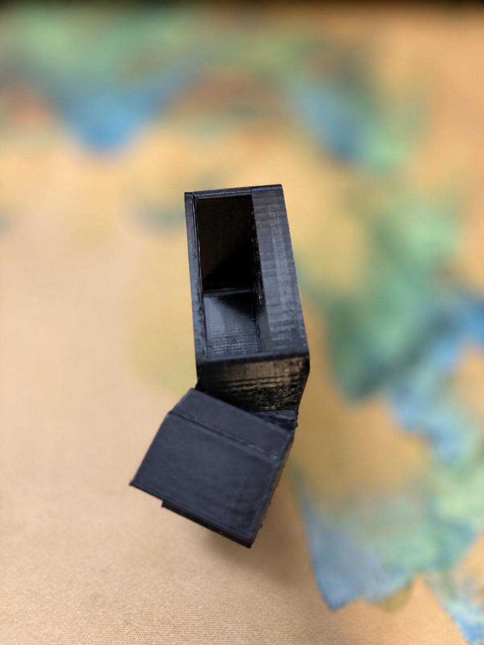
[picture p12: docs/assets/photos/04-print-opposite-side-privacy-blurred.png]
Printed mount opposite side
| Printed camera cradle |  |

## Redesigned 30° mount installed / 改造30°安装效果

### Rear and screw views / 背面与螺丝

| Rear-left / 左后 | Rear-right / 右后 |
| --- | --- |
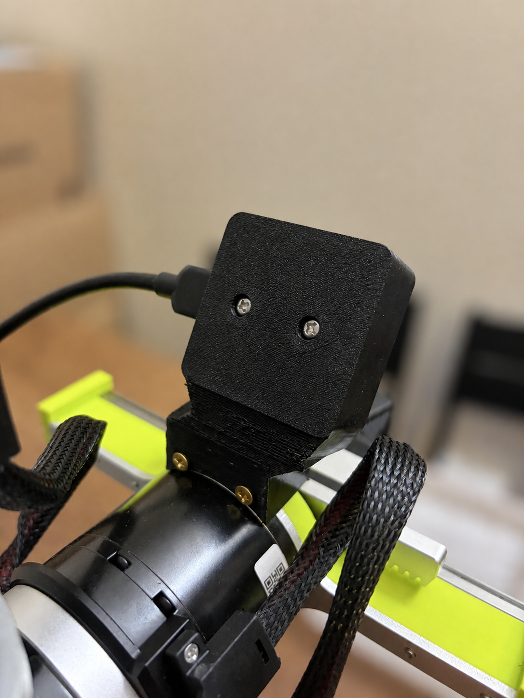
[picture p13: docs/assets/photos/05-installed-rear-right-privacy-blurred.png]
Installed rear-right
| Installed rear-left |  |

### Front and gripper relationship / 正面与夹爪关系

| Low front / 正面低视角 | Front-left / 左前 |
| --- | --- |
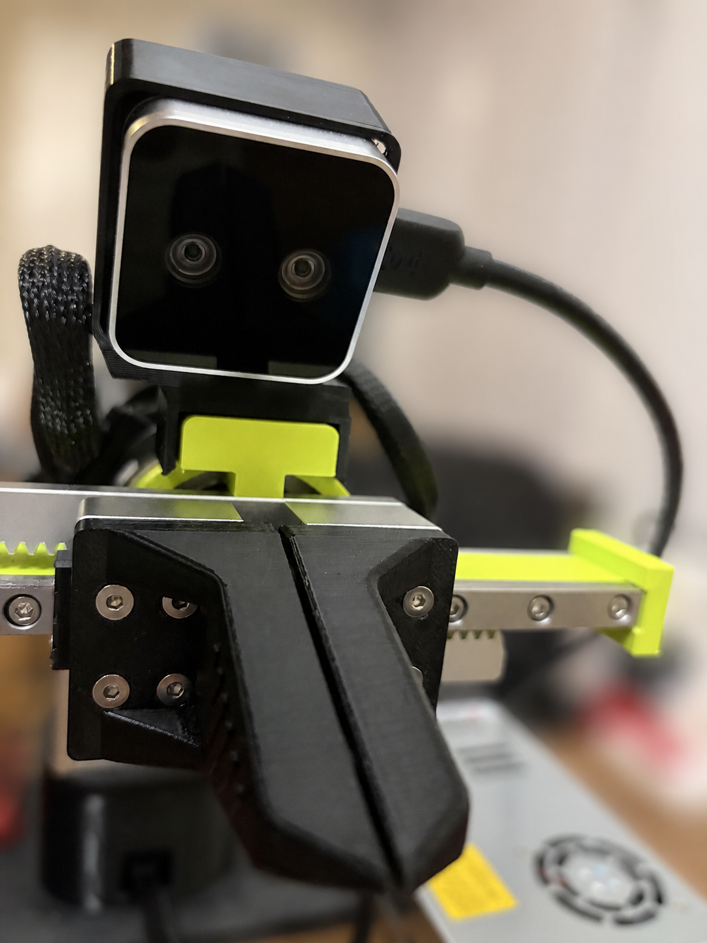
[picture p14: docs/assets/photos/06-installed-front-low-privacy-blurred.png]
Installed front low
|  | Installed front-left |

### Side pitch, USB and cable access / 侧面俯角、USB与线缆

| Right side / 右侧 | USB side wide / USB侧广角 |
| --- | --- |
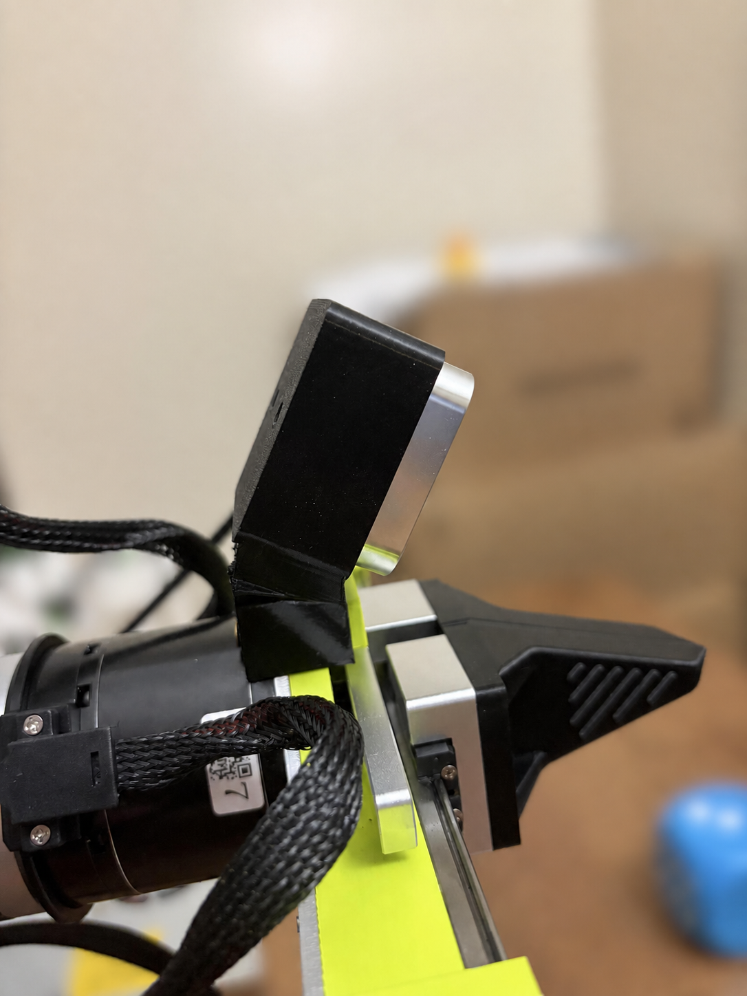
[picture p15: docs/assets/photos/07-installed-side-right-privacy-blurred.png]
Installed right side
|  | Installed USB side wide |

## Seeed-derived stock mount reference / Seeed派生原版参考

These six images show the earlier stock-angle mount based on Seeed's pinned [`D405_305_Mount.step`](https://github.com/Seeed-Projects/reBot-DevArm/blob/590ff16c51099a15a34abb339c6364355fde9235/hardware/reBot_B601_DM/3D_Printed_Parts/D405_305_Mount.step) and must not be mistaken for the redesigned 30° installation.

以下六张是基于Seeed固定版本[`D405_305_Mount.step`](https://github.com/Seeed-Projects/reBot-DevArm/blob/590ff16c51099a15a34abb339c6364355fde9235/hardware/reBot_B601_DM/3D_Printed_Parts/D405_305_Mount.step)的较早原版角度mount，不能与30°改造安装混淆。

| Front-right / 右前 | Front / 正面 |
| --- | --- |
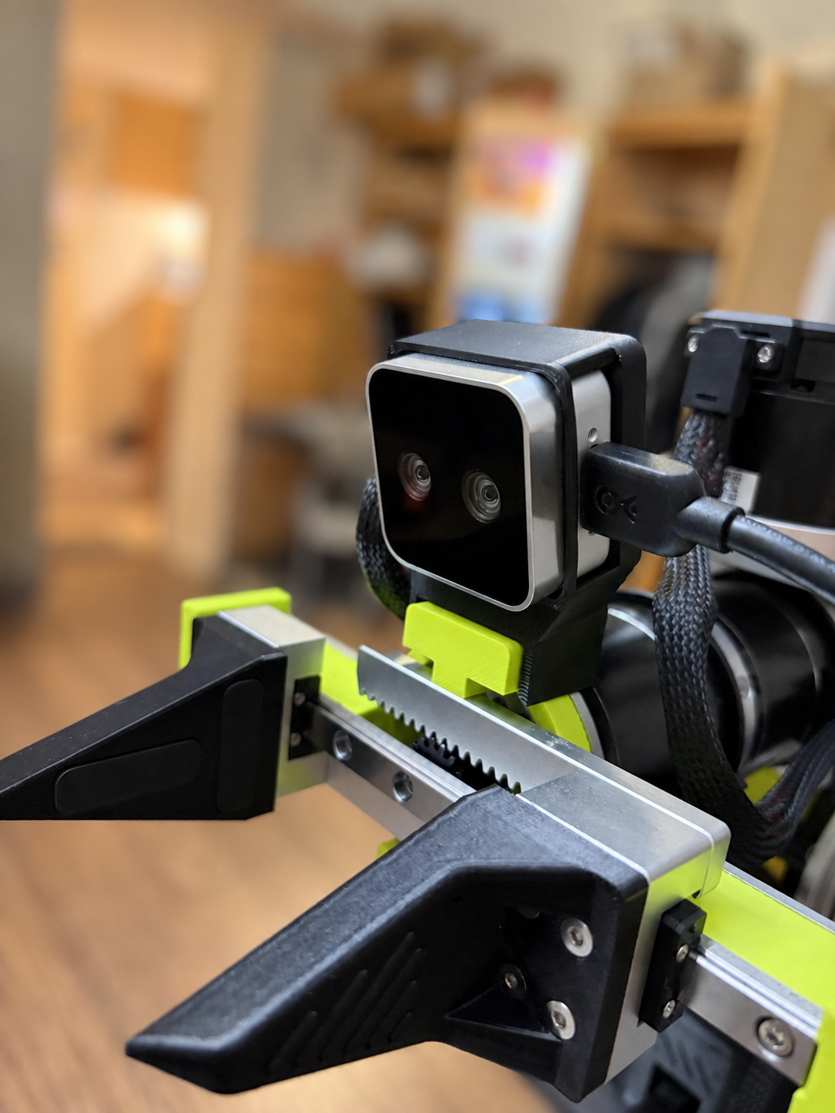
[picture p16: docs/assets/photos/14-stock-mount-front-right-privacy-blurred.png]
Stock mount front-right
|  | Stock mount front |

| Front wide / 正面广角 | Side-left / 左侧 |
| --- | --- |
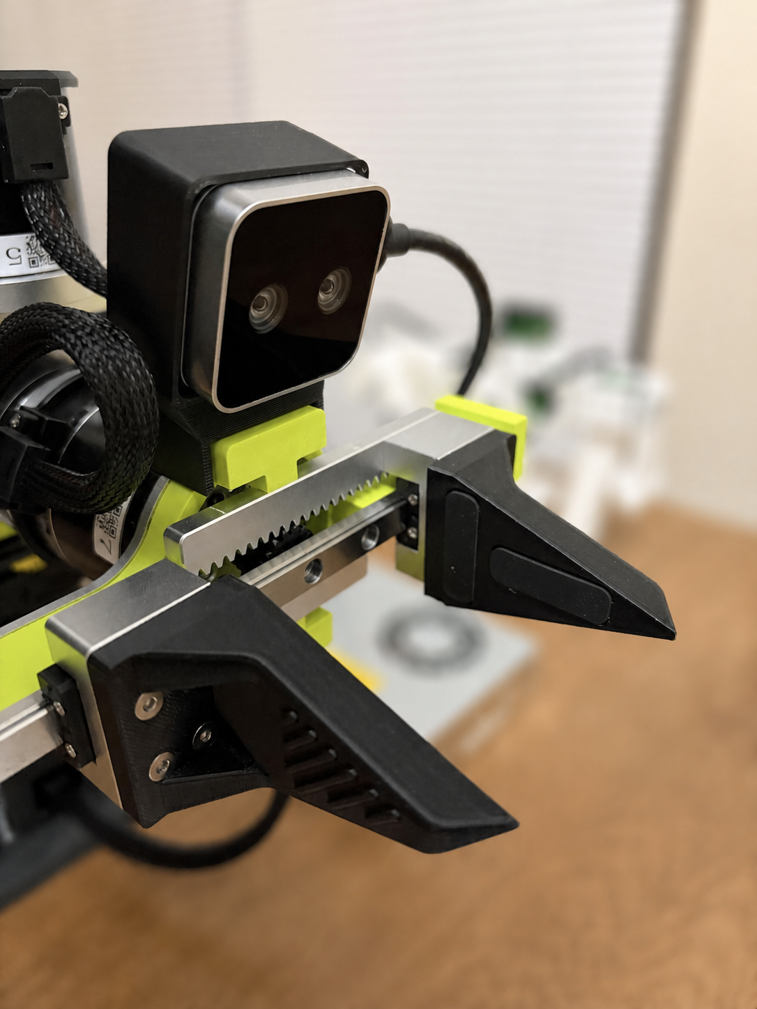
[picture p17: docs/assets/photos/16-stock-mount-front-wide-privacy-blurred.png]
Stock mount front wide
|  | Stock mount side-left |

| Rear / 背面 | Rear wide / 背面广角 |
| --- | --- |
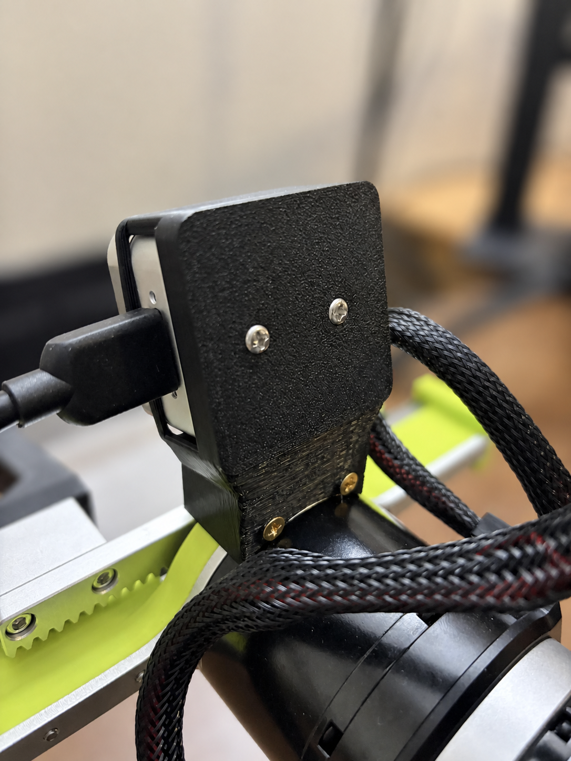
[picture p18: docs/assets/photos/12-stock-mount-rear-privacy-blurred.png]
Stock mount rear
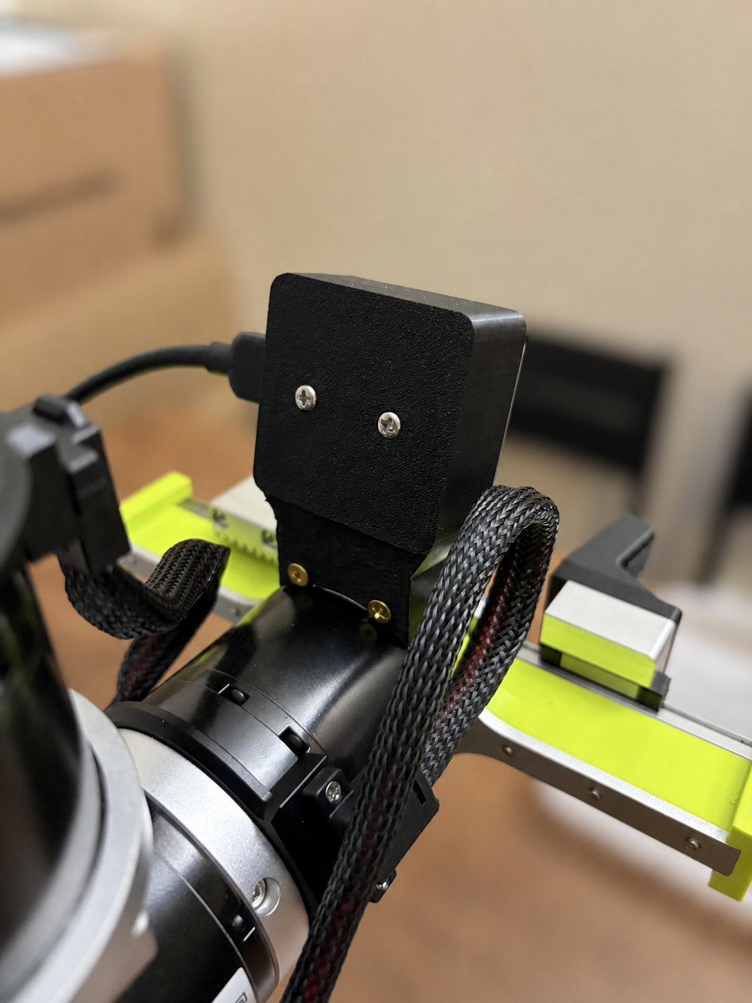
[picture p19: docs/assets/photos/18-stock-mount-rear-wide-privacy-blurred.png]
Stock mount rear wide
|  |  |

Photo authorship: Bowen Zhu. Photographs are licensed under CC BY 4.0; see [LICENSE.md](../LICENSE.md).

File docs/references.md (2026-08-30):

# Primary references

Accessed 2026-08-30 unless a pinned commit is shown.

## Seeed reBot B601-RS

1. **Seeed-Projects, reBot-DevArm** — official open-hardware repository and B601-DM/B601-RS project overview: <https://github.com/Seeed-Projects/reBot-DevArm>
2. **B601-RS hardware specification** — official RS hardware files, BOM, and print recommendations: <https://github.com/Seeed-Projects/reBot-DevArm/blob/main/hardware/reBot_B601_RS/README.md>
3. **reBot Arm B601-RS quick start** — official assembly/configuration entry point: <https://wiki.seeedstudio.com/rebot_b601_rs_getting_started/>
4. **Pinned Seeed source commit**: <https://github.com/Seeed-Projects/reBot-DevArm/tree/590ff16c51099a15a34abb339c6364355fde9235>
5. **Source D405 cradle at that commit**: <https://github.com/Seeed-Projects/reBot-DevArm/blob/590ff16c51099a15a34abb339c6364355fde9235/hardware/reBot_B601_DM/3D_Printed_Parts/D405_305_Mount.step>

The minimum vendored STEP and CERN-OHL-W-2.0 license are in [`hardware/vendor/seeed-rebot-devarm/`](../hardware/vendor/seeed-rebot-devarm/).

## RealSense D405

6. **RealSense D405 product page** — see “Small features, high impact → RGB without a dedicated RGB” and “Tech Specs → RGB → Technology” for 7–50 cm range, 87° × 58° depth FOV, global shutter, and “Left imager RGB with ISP”: <https://www.realsenseai.com/products/stereo-depth-camera-d405/>
7. **RealSense D400 Series Product Family Datasheet, Figure 10-13 on PDF page 146** — D405 dimensions, centered 20.00 mm M3 pair, 18 mm baseline, maximum insertion depth, Min-Z tables, and depth origin: <https://realsenseai.com/wp-content/uploads/2025/09/Intel-RealSense-D400-Series-Datasheet-October-2025.pdf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>
8. **D400 Calibration Tools User Guide, §2.1 “Calibration Parameters”** — states that the left camera is the reference camera and is located at world origin: <https://dev.realsenseai.com/docs/calibration-tools-user-guide-for-intel-realsense-d400-series/>
9. **Projection in RealSense SDK 2.0** — per-stream pixel and 3D coordinate systems: <https://dev.realsenseai.com/docs/projection-in-realsense-sdk-2-0/>
10. **D400 Depth Post-Processing, “2. Edge-preserving filtering”, occlusion paragraph** — explains that the stereo depth map is referenced to the left imager: <https://dev.realsenseai.com/docs/depth-post-processing-for-intel-realsense-depth-camera-d400-series/>

## Simulation

11. **ReBot_Arm_web_RS**, pinned local validation commit `d289fa7202ad7da9595a480b29397d70efacc4c1`: <https://github.com/Yang-Ci/ReBot_Arm_web_RS/tree/d289fa7202ad7da9595a480b29397d70efacc4c1>
12. **MuJoCo Python documentation**: <https://mujoco.readthedocs.io/en/stable/python.html>

The external robot project's pinned commit did not expose a repository-level license, so its model assets are not redistributed here. See [ATTRIBUTION.md](../ATTRIBUTION.md).

## Licensing

13. **CERN Open Hardware Licence Version 2 — Weakly Reciprocal**: <https://ohwr.org/cern_ohl_w_v2.txt>
14. **Creative Commons Attribution 4.0 International**: <https://creativecommons.org/licenses/by/4.0/>
15. **MIT License**: <https://opensource.org/license/mit>

## Local measured and generated evidence

Claims such as the exact 62.82° profile FOV, `(323.24, 235.99)` principal point, angle-sweep distances, mesh overlap volumes, and physical fit are local measurements or generated validation outputs—not claims copied from the linked sources. They are published in [`data/`](../data/), the release geometry JSON, and [validation.md](validation.md).

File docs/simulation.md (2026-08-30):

# MuJoCo reproduction

[简体中文](simulation.zh-CN.md)

## Purpose and boundary

The MuJoCo model answers first-order questions:

- where does the full D405 envelope sit relative to the green gripper structure?
- how does pitch change near-field visibility and gripper occlusion?
- does the tested design remain outside the 7 cm ideal near-range boundary at the proxy TCP targets?

It does **not** certify powered collision-free motion, estimate print deformation, or replace measured camera extrinsics.

## Why the robot model is not vendored

Validation used [`ReBot_Arm_web_RS@d289fa7202ad7da9595a480b29397d70efacc4c1`](https://github.com/Yang-Ci/ReBot_Arm_web_RS/tree/d289fa7202ad7da9595a480b29397d70efacc4c1). That commit did not expose a repository-level license, so its XML/URDF/mesh assets are deliberately not copied into this repository. Clone it separately and point the simulation to the scene XML.

## Setup

Generate the tested angle meshes in the dedicated CAD environment:

```bash
conda env create -f environment-cad.yml
conda activate rebot-d405-cad
python src/design_mount.py --angles 25 30 35
python src/validate_outputs.py --angles 25 30 35
```

Obtain the pinned robot scene:

```bash
git clone https://github.com/Yang-Ci/ReBot_Arm_web_RS.git external/ReBot_Arm_web_RS
git -C external/ReBot_Arm_web_RS checkout d289fa7202ad7da9595a480b29397d70efacc4c1
```

Create a **separate** MuJoCo environment; do not mix it with LeRobot or ROS system Python:

```bash
python3 -m venv .venv-sim
.venv-sim/bin/pip install -r requirements-simulation.txt
```

Run the rendered comparison and the 1° sweep:

```bash
export REBOT_MUJOCO_MODEL="$PWD/external/ReBot_Arm_web_RS/rebotarm_ros2/src/rebotarm_mujoco_rs/models/rs_grasp_scene.xml"
MUJOCO_GL=egl .venv-sim/bin/python simulation/simulate_fov.py
MUJOCO_GL=egl .venv-sim/bin/python simulation/sweep_angles.py
```

Outputs are written to ignored `build/`.

## Camera model

- D405 body envelope: 42 × 42 × 23 mm with a rounded visual proxy and a sharp conservative collision box;
- optical reference: left imager, 9 mm from the housing/stereo midpoint;
- optical start point behind front glass: 3.7 mm in the model;
- physical 640×480 color vertical FOV: 62.82°;
- physical principal point: approximately `(323.24, 235.99)` pixels;
- MuJoCo principal point: centered, a documented approximation.

## Published outputs

Controlled synthetic RGB/depth at the same grasp pose:

Stock 15 degree versus redesigned 30 degree synthetic RGB and depth

Historical camera-only stress screen (15°/25°/35°/45°; it intentionally omits the printable mount mesh):

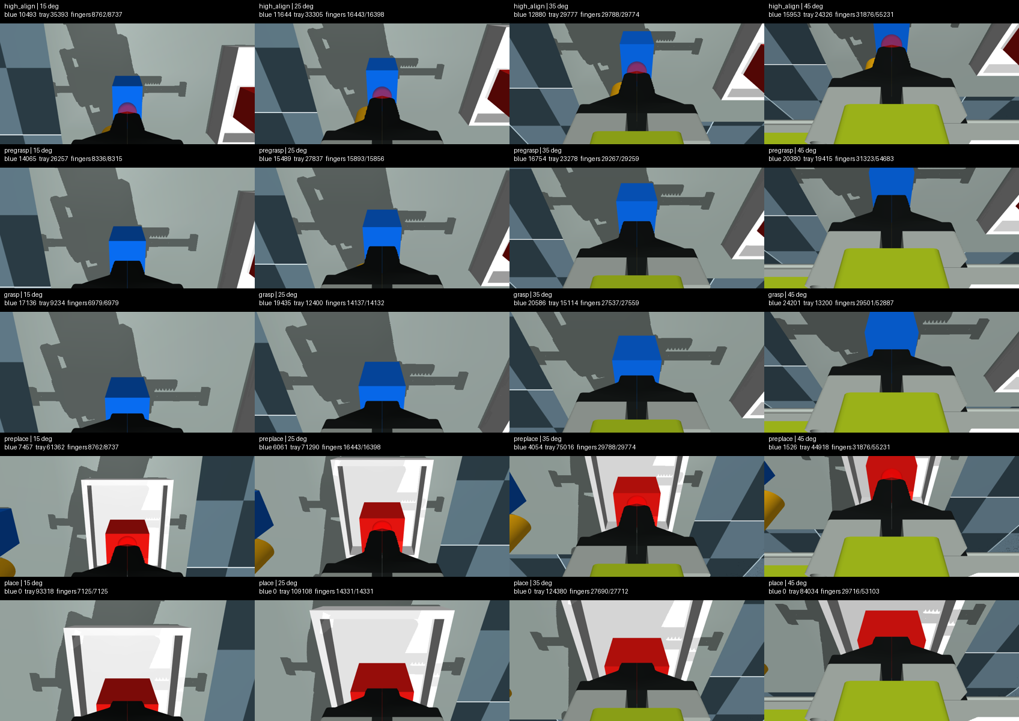
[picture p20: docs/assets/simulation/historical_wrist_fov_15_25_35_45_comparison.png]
Coarse FOV comparison


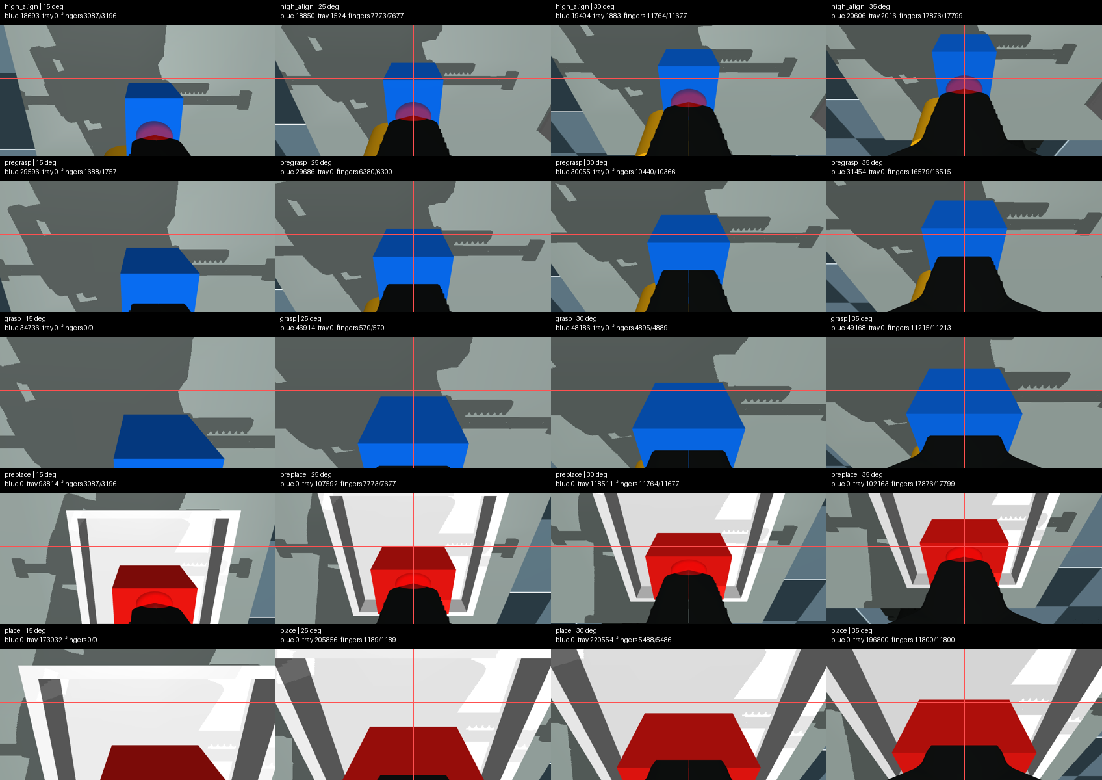
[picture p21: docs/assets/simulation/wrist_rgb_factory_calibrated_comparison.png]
Tested wrist-camera views


External assembly/clearance views

The corresponding CSV files are in [`data/`](../data/). Simulation screenshots contain visual assets from the external robot project and are not relicensed under this repository's CC BY terms; see [LICENSE.md](../LICENSE.md).

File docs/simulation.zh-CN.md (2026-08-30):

# MuJoCo 仿真复现

[English](simulation.md)

## 用途与边界

MuJoCo 用于回答第一阶问题：

- 完整 D405 包络相对绿色夹爪结构在哪里？
- 俯角如何改变近场可见性和夹爪遮挡？
- 在代理TCP目标上，30°设计是否仍位于7 cm理想近界之外？

它**不能**认证通电运动无碰撞、预测打印变形，也不能替代实测相机外参。

## 为什么没有把机器人模型复制进来

验证使用 [`ReBot_Arm_web_RS@d289fa7202ad7da9595a480b29397d70efacc4c1`](https://github.com/Yang-Ci/ReBot_Arm_web_RS/tree/d289fa7202ad7da9595a480b29397d70efacc4c1)。该commit没有仓库级许可证，因此这里不复制它的XML/URDF/mesh。用户需要单独clone并把仿真指向scene XML。

## 配置

在独立CAD环境生成测试角度mesh：

```bash
conda env create -f environment-cad.yml
conda activate rebot-d405-cad
python src/design_mount.py --angles 25 30 35
python src/validate_outputs.py --angles 25 30 35
```

获取固定版本机器人场景：

```bash
git clone https://github.com/Yang-Ci/ReBot_Arm_web_RS.git external/ReBot_Arm_web_RS
git -C external/ReBot_Arm_web_RS checkout d289fa7202ad7da9595a480b29397d70efacc4c1
```

新建**单独的** MuJoCo 环境，不要与 LeRobot 或 ROS 系统Python混用：

```bash
python3 -m venv .venv-sim
.venv-sim/bin/pip install -r requirements-simulation.txt
```

运行渲染对比和1°扫描：

```bash
export REBOT_MUJOCO_MODEL="$PWD/external/ReBot_Arm_web_RS/rebotarm_ros2/src/rebotarm_mujoco_rs/models/rs_grasp_scene.xml"
MUJOCO_GL=egl .venv-sim/bin/python simulation/simulate_fov.py
MUJOCO_GL=egl .venv-sim/bin/python simulation/sweep_angles.py
```

输出写入被忽略的 `build/`。

## 相机模型

- D405 包络：42 × 42 × 23 mm；视觉代理带圆角，碰撞检查额外使用尖角保守盒；
- 光学参考：左成像器，距离外壳/双目中点9 mm；
- 光学起点相对前玻璃：模型中3.7 mm；
- 实物640×480彩色垂直FOV：62.82°；
- 实物主点：约 `(323.24, 235.99)` 像素；
- MuJoCo 主点：居中，是明确记录的近似。

## 已发布输出

同一抓取姿态的受控synthetic RGB/Depth：

原版15度与改造30度synthetic RGB和Depth

历史相机代理压力筛查（15°/25°/35°/45°；有意不加载可打印mount mesh）：

粗粒度视野对比

测试腕上视角

外部装配与间隙

对应 CSV 位于 [`data/`](../data/)。仿真截图包含外部机器人项目的视觉资产，不在本仓库 CC BY 再许可范围内，详见 [LICENSE.md](../LICENSE.md)。

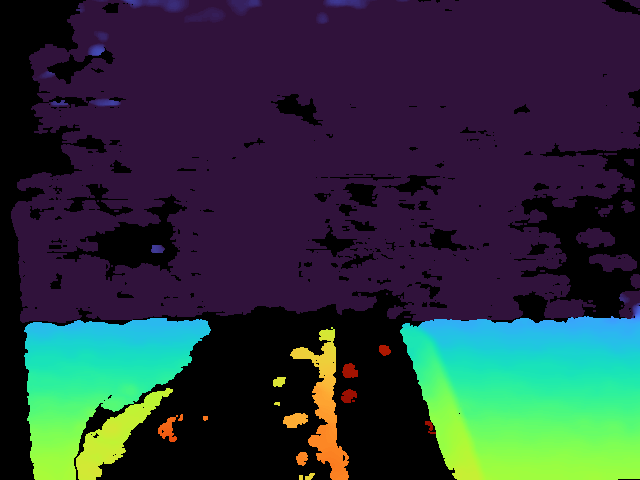
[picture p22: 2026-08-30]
docs/assets/camera/d405-redesigned30-depth-colorized.png

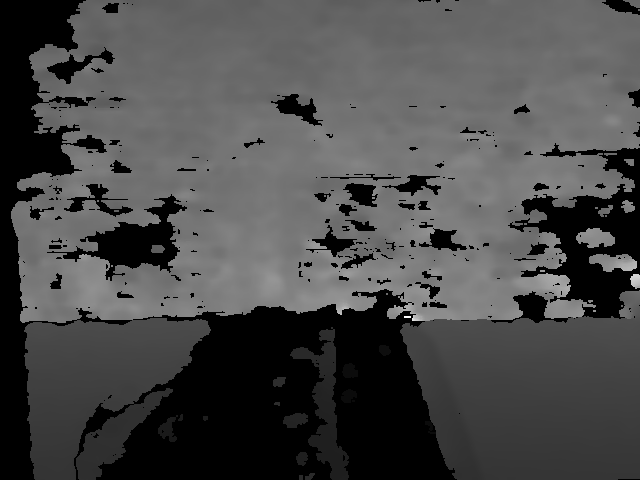
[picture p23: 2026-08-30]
docs/assets/camera/d405-redesigned30-depth-u16.png

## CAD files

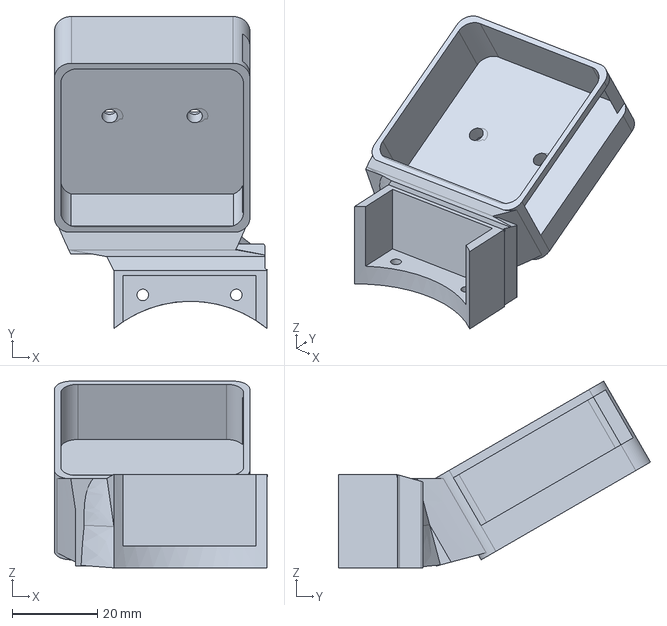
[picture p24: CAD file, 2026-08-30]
hardware/release/rebot_b601_rs_d405_mount_30deg.step
50.1 x 73.4 x 43.9 mm

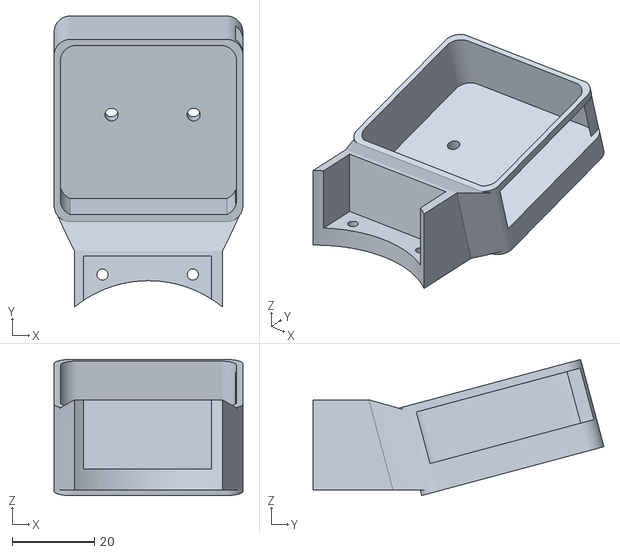
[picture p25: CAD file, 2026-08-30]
simulation/assets/seeed_original_d405_15deg.stl
46.0 x 70.9 x 33.2

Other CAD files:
hardware/release/rebot_b601_rs_d405_mount_30deg.stl

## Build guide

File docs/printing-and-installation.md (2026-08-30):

# Printing and installation

[简体中文](printing-and-installation.zh-CN.md)

## Choose the file

Prefer the STEP file when the manufacturing service accepts it; it preserves analytic geometry better than STL tessellation. Use the reviewed files in [`hardware/release/`](../hardware/release/), not intermediate angle outputs.

Use the single STEP/STL in `hardware/release/`. The 30° geometry was physically manufactured and installed; the published file incorporates the measured 1 mm rear-hole correction discovered during that installation.

## Material

| Material | Suggested use | Notes |
| --- | --- | --- |
| PETG | first fit-check and durable general use | good layer adhesion and impact resistance; usually less warp than ABS |
| ABS | lighter/stiffer production option | Seeed uses ABS for many structural B601 printed parts; control warping |
| PA12 MJF/SLS | premium option | good isotropy and fit, but frequently much more expensive |
| PLA | dimension-only prototype | not preferred for long-term wrist use because of heat/creep/impact limits |

Physically manufactured examples used PETG/100% and ABS/60%. A camera mount does not automatically benefit from 100% infill: wall count, layer orientation, screw regions, and transition geometry matter more than blindly maximizing mass. For a normal local FDM print, ABS or PETG at roughly 40–80% is a reasonable starting range.

Suggested slicer baseline:

- 0.4 mm nozzle;
- 0.2 mm layer height;
- 4 or more perimeters around screw and transition regions;
- supports where the selected orientation creates unsupported overhangs;
- inspect the two M3 passages and two B601 base holes in preview.

The online service used for the physically shown prints selected its own orientation/support plan. Do not infer a universal optimal orientation from surface lines in the photographs.

## Hardware

- 1× RealSense D405;
- 1× Seeed reBot Arm B601-RS with the compatible green gripper camera interface;
- 2× camera screws, starting check: M3×6 mm;
- 2× original B601 mount-interface screws;
- flexible USB 3 cable with sufficient wrist sweep length.

The D405 documentation specifies `2× M3×0.5` rear holes and a maximum 4.0 mm thread engagement. Measure the printed backplate and screw under-head length. A screw that bottoms internally can damage the camera even when the mount appears loose.

## Fit-check before robot installation

1. Keep robot motor power disconnected.
2. Inspect the print for cracks, delamination, blocked holes, thin flakes, and warped seating surfaces.
3. Insert the D405 without screws. It should fully seat against the inherited bottom/side/top cradle without excessive force.
4. Verify that the USB connector can enter and leave without rubbing the printed opening.
5. Install the two camera screws loosely, seat the camera, then tighten alternately in small increments.
6. Confirm that screw heads clamp the backplate and do not bottom in the camera.
7. Lightly push the camera in multiple directions. There should be no rocking or clicking.

The 3.6 mm passages are clearance holes; they do not thread into the plastic. Camera registration comes from the full cradle surfaces plus screw clamping.

## Install on the B601-RS

1. Disconnect motor power and support the wrist/gripper.
2. Place the mount on the green interface with the USB opening on the physical D405 connector side.
3. Start both base screws before tightening either one fully.
4. Check that the base is flush and the filled transition does not touch moving gripper components.
5. Connect USB and establish a relaxed service loop. Do not allow the connector to carry cable tension.
6. Manually open and close the gripper and slowly sweep reachable wrist motion while unpowered, watching the USB lead and braided motor harnesses.
7. Capture a camera frame and verify orientation, gripper centering, vignetting, exposure, and focus.

## After installation

- For RGB research, freeze the mechanical mounting and record the mount version in dataset metadata.
- For metric RGB-D work, calibrate intrinsics/profile and the installed camera-to-tool/robot transform. Do not treat nominal CAD pose as measured extrinsics.
- Recheck screw preload and image stability after initial manipulation trials.
- Stop immediately if the camera shifts, the print cracks, a cable becomes taut, or the mount approaches another robot part.

## Physical photographs

See [photo gallery](photo-gallery.md). Use CAD, not photograph pixels, for dimensions.

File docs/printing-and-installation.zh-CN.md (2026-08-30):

# 打印与安装

[English](printing-and-installation.md)

## 选择文件

打印平台支持 STEP 时优先上传 STEP，因为它比 STL 三角网格更好地保留解析几何。只使用 [`hardware/release/`](../hardware/release/) 中审核过的文件，不要误用中间角度输出。

使用`hardware/release/`中的STEP/STL。30°几何已经实际制造并安装；发布文件包含这次安装发现的后部孔位1 mm实测修正。

## 材料

| 材料 | 建议用途 | 说明 |
| --- | --- | --- |
| PETG | 首件适配和耐用通用件 | 层间结合和抗冲击较好，通常比ABS更不易翘曲 |
| ABS | 更轻、更硬的生产候选 | Seeed 的许多 B601 结构打印件使用ABS；需要控制翘曲 |
| PA12 MJF/SLS | 高价方案 | 各向同性和适配较好，但常常明显更贵 |
| PLA | 只做廉价尺寸样件 | 耐热、蠕变和抗冲击不适合长期腕部使用 |

实物使用了 PETG/100% 与 ABS/60%。相机支架并不会因100%填充自动更好；壁数、层方向、螺丝区域和过渡几何通常比盲目增重更重要。普通本地 FDM 可从 ABS/PETG 40%–80% 左右开始。

切片基线建议：

- 0.4 mm 喷嘴；
- 0.2 mm 层高；
- 螺丝与过渡区域至少4圈外壁；
- 按打印方向为悬空部分添加支撑；
- 在预览中检查两条 M3 通道和两颗 B601 底座孔。

实拍件由在线打印服务自行决定打印方向和支撑。不能根据照片层纹推断通用最优方向。

## 所需硬件

- 1× RealSense D405；
- 1× 带兼容绿色夹爪相机接口的 Seeed reBot Arm B601-RS；
- 2× 相机螺丝，建议先核对 M3×6 mm；
- 2× B601 原接口螺丝；
- 足够长且柔软的 USB 3 线。

D405 官方标注后部为 `2× M3×0.5`，最大旋入深度4.0 mm。必须实测背板厚度和螺丝头下长度。过长螺丝可能在相机内部顶死并造成损伤，即使外观看起来仍然松。

## 装到机械臂前的适配检查

1. 保持机械臂电机主电源断开。
2. 检查裂纹、分层、堵孔、薄碎边和翘曲定位面。
3. 不装螺丝先放入D405；应能完整坐在原版底部/侧面/顶部托架内，不能强行硬压。
4. 确认USB能正常插拔且不摩擦开口。
5. 两颗相机螺丝先松装，让相机贴合定位面，再交替小幅拧紧。
6. 确认螺丝头压住背板且没有在相机内顶死。
7. 从多个方向轻推相机，不应晃动或发出咔哒声。

3.6 mm 是通孔，不在塑料内咬螺纹；相机位置由完整托架定位面和螺丝夹紧共同确定。

## 安装到 B601-RS

1. 断开电机主电源并托住腕部/夹爪。
2. 按D405真实USB插口方向把mount放到绿色接口上。
3. 两颗底座螺丝都先入牙，再逐步拧紧，不能先锁死一侧。
4. 确认底座贴合，实心过渡体不碰夹爪运动件。
5. 插入USB并留出松弛服务环，不能让插头承受线缆拉力。
6. 断电状态手动完整开合夹爪，并缓慢扫过可达腕部范围，观察USB线和编织电机线束。
7. 抓取相机画面，检查方向、夹爪居中、遮挡、曝光和对焦。

## 安装后

- RGB研究应冻结机械安装，并在dataset元数据中记录mount版本。
- metric RGB-D研究必须标定实际profile、内参与相机到tool/机器人外参；不能把CAD名义位姿当成实测真值。
- 首轮操作后重新检查螺丝预紧和画面稳定性。
- 相机位移、打印件开裂、线缆拉紧或mount接近其他结构时立即停止。

实拍见[图库](photo-gallery.md)。尺寸请以CAD为准。

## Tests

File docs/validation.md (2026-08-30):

# Validation

[简体中文](validation.zh-CN.md)

## Validation layers

This project keeps four kinds of evidence separate. Passing one layer does not imply the next.

1. **CAD topology:** solid validity, holes, dimensions, inherited cradle equivalence.
2. **Mesh integrity:** connected, closed, manifold STL.
3. **MuJoCo screening:** first-order D405 envelope clearance, working distance, and rendered visibility.
4. **Physical acceptance:** print fit, screw assembly, USB access, and live camera framing.

## Automated CAD checks

`src/design_mount.py` and `src/validate_outputs.py` require:

- one valid STEP solid;
- one connected STL region;
- zero boundary and non-manifold STL edges;
- unblocked D405 and B601 screw passages;
- unchanged complete cradle geometry before rigid transformation;
- unchanged source handedness and correct USB opening side;
- substantial solid overlap between transition/base and transition/cradle;
- zero added adapter collision with the D405 engineering envelope;
- exact 20.000 mm D405 screw-axis spacing;
- metadata flags for the filled transition, shift, hole clearances, and no mirroring.

30° geometry results:

| Metric | Result |
| --- | ---: |
| STEP solids | 1 |
| STEP volume | ~32,475.6 mm³ |
| D405 screw-axis spacing | 20.000 mm |
| through/counterbore diameters | 3.6 / 6.0 mm |
| lateral cradle shift | −9.0 mm |
| Seeed source M3-pair offset | +1.000 mm |
| hole correction | −1.000 mm |
| source-hole fill volume | ~212.1 mm³ |
| new adapter–D405 collision | 0.0000 mm³ |
| adapter–base overlap | ~2,002 mm³ |
| adapter–cradle overlap | ~751 mm³ |

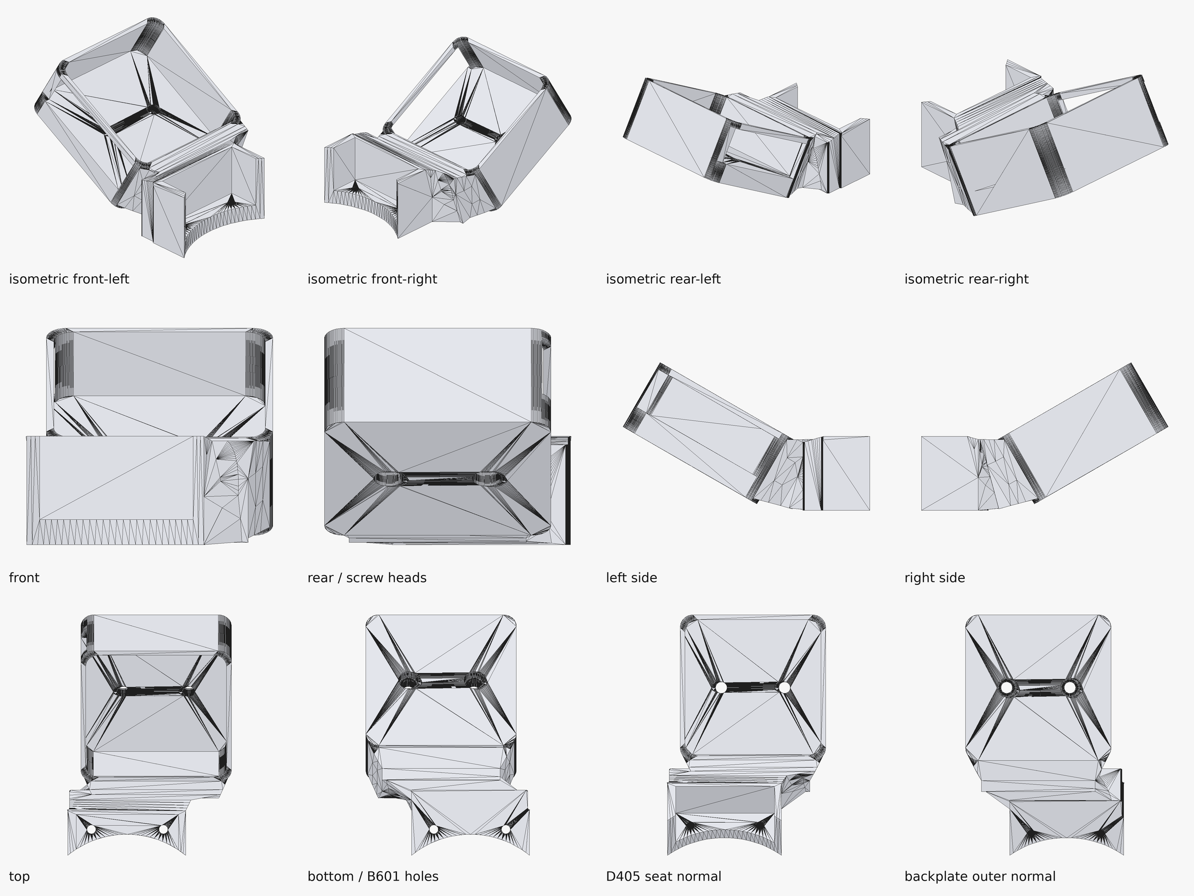
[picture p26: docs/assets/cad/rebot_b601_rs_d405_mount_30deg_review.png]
Corrected CAD review


## MuJoCo screen

The local validation used [`ReBot_Arm_web_RS@d289fa7202ad7da9595a480b29397d70efacc4c1`](https://github.com/Yang-Ci/ReBot_Arm_web_RS/tree/d289fa7202ad7da9595a480b29397d70efacc4c1). The full-size D405 envelope and actual generated mount meshes were attached at the B601 screw-axis datum.

Conservative D405-to-green-part clearances:

| Pitch | Clearance |
| ---: | ---: |
| stock 15° | 9.17 mm |
| 25° | 11.17 mm |
| 29° | 9.53 mm |
| **30°** | **9.12 mm** |
| 35° | 7.06 mm |

External MuJoCo assembly views

The image below uses the physical camera's 640×480 calibration to compare wrist views at several tested pitches. The crosshair and task proxies support interpretation, but task-specific tray/cube pixels are not the angle selector.

Factory-calibrated wrist views

Limitations:

- simplified rounded D405 housing, not manufacturing CAD for every chamfer;
- MuJoCo centered principal point, so small principal-point/lens-distortion residuals are omitted;
- scene and IK poses are screening proxies;
- mesh distance is not a tolerance stack-up or powered collision certificate.

## Physical print and installation

Two FDM material configurations were produced: PETG 100% infill and ABS 60% infill. The gallery includes the print and installation views.

Physical observations below apply to the manufactured and installed 30° design. That installation exposed the inherited 1 mm hole offset; the release incorporates the measured correction:

- the printed part is continuous across the filled transition;
- the D405 seats inside the inherited full cradle;
- both camera screws and both B601 interface screws assemble;
- USB-C remains accessible from the correct side;
- no mount material occludes the front imagers;
- the installed pitch and cradle clearance visually agree with the modeled orientation;
- a 640×480 D405 RGB frame placed the gripper centerline approximately at image center, supporting the 9 mm shift direction.

The corrected geometry passes the same CAD and MuJoCo checks, plus an export-level assertion that only the two corrected through/counterbore axes remain.

Installed rear view

## Physical D405 output

The comparison below uses uncropped 640×480 frames output by the installed D405. The stock-mount source is an RGB frame extracted at 10.0 s from a 2026-08-24 recording. The redesigned-mount source is a synchronized RGB/depth capture from 2026-08-30 after 120 warm-up frames; depth was aligned to RGB and retained as a raw 16-bit PNG as well as a 0.04–0.50 m colorized view.

Physical D405 output comparison

This supports the qualitative framing claim: the redesigned view centers the gripper and includes more of the near workspace. It does **not** establish a quantitative optical improvement because the dates, illumination, and robot poses were not controlled. Historical depth was not recorded. Exact source paths, timestamps, hashes, intrinsics, depth scale, and valid-pixel fraction are in [`data/physical_d405_capture_provenance.json`](../data/physical_d405_capture_provenance.json).

## Not yet claimed

- powered full-joint collision sweep;
- quantified vibration comparison between PETG and ABS;
- repeated remove/reinstall extrinsic repeatability;
- repeat-manufacturing measurement of corrected screw centering;
- 30-minute temperature logging at maximum stream load;
- metric RGB-D extrinsic calibration to the robot/tool frame.

These are future validation tasks, not silent assumptions.

## Reproduce

CAD:

```bash
conda env create -f environment-cad.yml
conda activate rebot-d405-cad
python src/design_mount.py --angles 25 29 30 35
python src/validate_outputs.py --angles 25 29 30 35
```

Fast repository integrity check:

```bash
python tools/check_repository.py
```

Optional read-only physical RGB-D capture (this opens only the named camera and does not connect to the robot or CAN):

```bash
python tools/capture_d405_rgbd.py --serial <D405_SERIAL> --output-dir capture-output
python tools/build_physical_camera_comparison.py \
  --redesigned-rgb capture-output/d405-rgb.png \
  --redesigned-depth-colorized capture-output/d405-depth-colorized.png \
  --output capture-output/d405-physical-output-comparison.png
```

The capture helper requires `pyrealsense2`, NumPy, and OpenCV. The comparison builder uses Pillow from `environment-cad.yml`.

MuJoCo reproduction is documented in [simulation.md](simulation.md). Machine-readable data are in [`data/`](../data/).

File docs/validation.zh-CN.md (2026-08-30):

# 验证记录

[English](validation.md)

## 四层证据不能混用

1. **CAD 拓扑**：实体有效性、孔位、尺寸、原版托架等价性。
2. **Mesh 完整性**：STL 单连通、封闭、无非流形边。
3. **MuJoCo 筛查**：D405 包络间隙、工作距离和第一阶视野。
4. **真机验收**：打印适配、螺丝装配、USB 插拔和真实相机画面。

上一层通过不代表下一层自动通过。

## 自动 CAD 检查

`src/design_mount.py` 与 `src/validate_outputs.py` 要求：

- STEP 只有一个有效实体；
- STL 只有一个连通区域；
- STL 边界边和非流形边均为零；
- D405 与 B601 四条螺丝通道没有被堵；
- 原版完整托架在刚体变换前几何完全等价；
- 左右方向不变，USB 开口侧正确；
- 过渡体与底座、托架都有较大实体搭接；
- 新增过渡体对 D405 工程包络碰撞为零；
- D405 两螺丝轴距保持 20.000 mm；
- 元数据记录实心过渡、平移、孔径和未镜像状态。

30°几何结果：

| 指标 | 结果 |
| --- | ---: |
| STEP 实体数 | 1 |
| STEP 体积 | ~32,475.6 mm³ |
| D405 螺丝轴距 | 20.000 mm |
| 通孔/沉孔直径 | 3.6 / 6.0 mm |
| 托架横向平移 | −9.0 mm |
| Seeed源M3孔对偏移 | +1.000 mm |
| 孔位修正 | −1.000 mm |
| 源孔填回体积 | ~212.1 mm³ |
| 新过渡体–D405碰撞 | 0.0000 mm³ |
| 过渡体–底座搭接 | ~2,002 mm³ |
| 过渡体–托架搭接 | ~751 mm³ |

修正CAD审阅图

## MuJoCo 筛查

本地验证使用[`ReBot_Arm_web_RS@d289fa7202ad7da9595a480b29397d70efacc4c1`](https://github.com/Yang-Ci/ReBot_Arm_web_RS/tree/d289fa7202ad7da9595a480b29397d70efacc4c1)，以B601真实螺丝轴线基准挂载完整D405包络和实际生成的mount mesh。

保守 D405–绿色件间隙：

| 俯角 | 间隙 |
| ---: | ---: |
| 原版15° | 9.17 mm |
| 25° | 11.17 mm |
| 29° | 9.53 mm |
| **30°** | **9.12 mm** |
| 35° | 7.06 mm |

MuJoCo 外部装配视图

下面的视图使用实物D405 640×480标定参数比较多个测试角度。十字线和任务代理帮助理解画面，但托盘/方块像素面积不是通用角度的选择依据。

实机标定视野对比

局限：

- D405 使用带圆角工程包络，不是每个倒角都精确的制造模型；
- MuJoCo 主点居中，忽略少量主点偏差和镜头畸变；
- 场景和 IK 姿态是筛查代理；
- mesh 距离不是公差堆栈，也不是通电碰撞认证。

## 打印与安装实证

实际制造了PETG 100%和ABS 60%两种FDM材料配置。图库包含打印件和安装视图。

以下照片和真实相机结论对应实际制造、安装的30°设计。这次安装暴露了上游1 mm孔偏移；发布件已经收入实测修正。

- 实心过渡部分连续成形；
- D405 能完整坐入继承自原版的托架；
- 两颗相机螺丝和两颗 B601 接口螺丝均可装配；
- USB-C 能从正确一侧正常插入；
- mount 不遮挡相机正面成像器；
- 安装俯角和可见间隙与仿真方向一致；
- D405 640×480 RGB 中夹爪中心线基本位于画面中心，支持9 mm平移方向正确。

修正几何通过同样的CAD和MuJoCo检查，并额外断言导出STEP中只能保留两条修正通孔/沉孔轴。

安装背面

## D405真实输出

下图使用安装在机械臂上的D405直接输出、未经裁剪的640×480帧。原版支架来源是2026-08-24录像第10.0秒提取的RGB；改造支架来源是2026-08-30在预热120帧后采集的同步RGB/Depth。Depth对齐到RGB，同时保留16位原始PNG和0.04–0.50 m彩色可视化。

D405真实输出对比

这些证据支持定性视野结论：改造画面让夹爪居中，并包含更多近场工作区。由于采集日期、照明和机械臂姿态均未受控，它**不能**证明定量光学提升；历史记录也没有Depth。准确来源路径、时间、哈希、内参、Depth scale和有效像素比例见[`data/physical_d405_capture_provenance.json`](../data/physical_d405_capture_provenance.json)。

## 目前不声称已经完成

- 全关节通电碰撞扫掠；
- PETG 与 ABS 振动的量化比较；
- 反复拆装后的外参重复性；
- 修正孔位的重复制造测量；
- 最大流负载下30分钟温升记录；
- 相机到机器人/tool frame 的 metric RGB-D 外参标定。

这些是后续验证任务，不能当作默认已经通过。

## 复现

CAD：

```bash
conda env create -f environment-cad.yml
conda activate rebot-d405-cad
python src/design_mount.py --angles 25 29 30 35
python src/validate_outputs.py --angles 25 29 30 35
```

仓库快速完整性检查：

```bash
python tools/check_repository.py
```

可选的只读真机RGB-D采集（脚本只打开指定相机，不连接机械臂或CAN）：

```bash
python tools/capture_d405_rgbd.py --serial <D405_SERIAL> --output-dir capture-output
python tools/build_physical_camera_comparison.py \
  --redesigned-rgb capture-output/d405-rgb.png \
  --redesigned-depth-colorized capture-output/d405-depth-colorized.png \
  --output capture-output/d405-physical-output-comparison.png
```

采集脚本需要`pyrealsense2`、NumPy和OpenCV；对比图生成脚本使用`environment-cad.yml`中的Pillow。

MuJoCo 复现见 [simulation.zh-CN.md](simulation.zh-CN.md)，机器可读数据位于 [`data/`](../data/)。

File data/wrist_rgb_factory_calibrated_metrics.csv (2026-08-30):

stage | angle_deg | d405_green_clearance_mm | ik_position_error_mm | ik_rotation_error_deg | blue_px | blue_cx | blue_cy | tray_px | tray_cx | tray_cy | left_finger_px | left_finger_cx | left_finger_cy | right_finger_px | right_finger_cx | right_finger_cy
high_align | 15.0 | 9.174489448818566 | 2.6864074493232733e-11 | 3.1930532139735253e-13 | 18693 | 352.99625528272617 | 333.43470817953244 | 0 | nan | nan | 3087 | 398.94493035309364 | 455.3530936183997 | 3196 | 336.07509386733415 | 455.5578848560701
high_align | 25.0 | 11.166786383304487 | 2.6864074493232733e-11 | 3.1930532139735253e-13 | 18850 | 319.5 | 269.29050397877984 | 1524 | 629.6935695538058 | 392.4422572178478 | 7773 | 355.50533899395344 | 428.8523092756979 | 7677 | 283.9766836003647 | 428.740263123616
high_align | 30.0 | 9.123410090200366 | 2.6864074493232733e-11 | 3.1930532139735253e-13 | 19404 | 319.5 | 227.1480107194393 | 1883 | 628.0212426978226 | 354.4057355284121 | 11764 | 359.4075994559674 | 411.1473138388303 | 11677 | 279.86708914961036 | 411.227113128372
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

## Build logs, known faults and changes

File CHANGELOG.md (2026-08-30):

# Changelog

## 1.0.0 — 2026-08-30

- First standalone bilingual release for the Seeed reBot B601-RS / RealSense D405 30° wrist mount.
- Publishes one STEP/STL/geometry set.
- Documents and corrects the pinned Seeed source's +1.000 mm rear M3-pair offset.
- Includes 20°–36° MuJoCo screening, a controlled synthetic RGB/depth comparison, physical D405 output frames with raw 16-bit depth provenance, manufacturing/installation photographs, source links, and reproducible validation.
